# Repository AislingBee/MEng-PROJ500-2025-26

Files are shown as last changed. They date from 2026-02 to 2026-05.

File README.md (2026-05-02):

# MEng-PROJ500-2025-26

Main repository for the PROJ500 humanoid robot project.

Project timeline: December 2025 to May 2026.

## Start Here

1. Read this file for the project map.
2. Read [README_PROJECT_MAP.md](README_PROJECT_MAP.md) for a top-level file/folder map.
3. Read [README_IMPORTANT_PATHS.md](README_IMPORTANT_PATHS.md) for key entrypoints and files.
4. Read [README_QUICKSTART.md](README_QUICKSTART.md) for launch order and runtime checks.
5. For simulation and Isaac workflow, read [simulation/README.md](simulation/README.md).
6. For ROS2 motor stack, read [Software/src/motor_control/README.md](Software/src/motor_control/README.md).
7. For the RCU UDP protocol handover, read [Charlie/STM32Cube/Tools/ROS2/HANDOVER_INSTRUCTIONS.md](Charlie/STM32Cube/Tools/ROS2/HANDOVER_INSTRUCTIONS.md).

## Top-Level Repository Overview

## New STM32 Addition (RCU UDP Bridge)

The current hardware path now supports a direct STM32 RCU UDP binary bridge.

- New bridge node: [Software/src/motor_control/motor_control/bridges/rcu_udp_bridge.py](Software/src/motor_control/motor_control/bridges/rcu_udp_bridge.py)
- RCU launch entrypoint: [Software/src/motor_control/launch/rcu_launch.py](Software/src/motor_control/launch/rcu_launch.py)
- Full RL launch (with RCU transport): [Software/src/motor_control/launch/rl_robot_launch.py](Software/src/motor_control/launch/rl_robot_launch.py)
- Protocol reference and handover: [Charlie/STM32Cube/Tools/ROS2/HANDOVER_INSTRUCTIONS.md](Charlie/STM32Cube/Tools/ROS2/HANDOVER_INSTRUCTIONS.md)

RCU network defaults:

- RCU IP: `192.168.100.10`
- Thor host IP: `192.168.100.20/24`
- Telemetry in: UDP `7700`
- Command out: UDP `7701`
- Supervision out: UDP `7702`

The Software Nucleo bridge path has been removed; RCU UDP is now the primary integration path.

### Core folders

- [simulation](simulation): Isaac Sim assets, tools, and RL workspace.
  - Further docs:
  - [simulation/README.md](simulation/README.md)
  - [simulation/docs/README.md](simulation/docs/README.md)
  - [simulation/isaac/README.md](simulation/isaac/README.md)
  - [simulation/isaac/rl/README.md](simulation/isaac/rl/README.md)

- [Software](Software): software stack for firmware, bridge tools, ROS2 motor test package, and configs.
  - ROS2 motor package:
  - [Software/src/motor_control/README.md](Software/src/motor_control/README.md)
  - Integration guide:
  - [Software/ROS_STM32_INTEGRATION.md](Software/ROS_STM32_INTEGRATION.md)

### Top-level files

- [README.md](README.md): this overview.
- [joint_limit_results.csv](joint_limit_results.csv): saved joint limit validation/test output.
- [hardware/thor/thor_policy_runner.py](hardware/thor/thor_policy_runner.py): policy runtime script.
- [power_shell_commands](power_shell_commands): command notes and helper snippets.

## Software Folder Details

Within [Software](Software):

- [Software/config](Software/config): shared config files (including JSON config used by launch files).
- [Software/nucleo](Software/nucleo): motor protocol notes/manual assets and experimental scripts.
- [Software/src/motor_control](Software/src/motor_control): ROS2 package for command generation, bridges, listeners, and launch files.

## Important Readme and Documentation Index

### Simulation and RL

- [simulation/README.md](simulation/README.md)
- [simulation/docs/README.md](simulation/docs/README.md)
- [simulation/isaac/README.md](simulation/isaac/README.md)
- [simulation/isaac/rl/README.md](simulation/isaac/rl/README.md)

### Firmware and Bridge

- [Software/ROS_STM32_INTEGRATION.md](Software/ROS_STM32_INTEGRATION.md)
- [Charlie/STM32Cube/Tools/ROS2/HANDOVER_INSTRUCTIONS.md](Charlie/STM32Cube/Tools/ROS2/HANDOVER_INSTRUCTIONS.md)

### ROS2 Motor Test

- [Software/src/motor_control/README.md](Software/src/motor_control/README.md)
- Launch files are in [Software/src/motor_control/launch](Software/src/motor_control/launch).
- Test and bridge nodes are in [Software/src/motor_control/motor_control](Software/src/motor_control/motor_control).

## Contribution Rules

- Do not push directly to main.
- Use feature branches and open a pull request.
- Include a clear summary of changes and test steps in each PR.
- Merge to main only after review.
- Delete merged branches.

## Commit and PR Conventions

- Use descriptive commit titles (example: Add ROS2 joint command bridge).
- Include test evidence in PR descriptions.
- Provide exact run steps and expected output for reviewers.

Example test flow:

```bash
cd Software/src/motor_control
colcon build --packages-select motor_control
source install/setup.bash
ros2 launch motor_control rl_robot_launch.py
```

## Team

- Mechanical Lead (Project Lead): Brendan
- Electrical Lead: Charlie
- Simulation Lead: Joe
- Software/ROS Lead: Ash

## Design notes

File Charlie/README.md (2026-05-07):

# PROJ500 Humanoid Robot — Charlie's Handover

**Author:** Charlie  
**Date:** May 2026  
**Project:** MEng PROJ500 — Plymouth Humanoid Robot  

This folder contains all hardware and firmware deliverables produced during the 2025–26 academic year. It is structured into three top-level areas:

```
Charlie/
├── KiCad/                  — PCB schematics and layouts (5 boards)
├── PROJ500_PDU_FPGA/       — Lattice MachXO2 FPGA project (PDU sequencer)
└── STM32Cube/              — STM32 firmware (PDU + RCU) and PC tools
```

---

## System Overview

The robot's electronic architecture is split across two custom boards:

| Board | MCU | Role |
|---|---|---|
| **PDU** — Power Distribution Unit | STM32G474 | Battery management, power sequencing, relay/contactor control via FPGA |
| **RCU** — Real-Time Control Unit | STM32H723 | Motor CAN buses, Ethernet UDP to Thor, dual IMU, PDU telemetry forwarding |

The PDU and RCU communicate over a dedicated **management CAN bus (250 kbps)**. The RCU talks to the Thor AI computer (Jetson/PC) over **UDP/Ethernet**. Motors are driven by the RCU over two **1 Mbps CAN buses** using the RobStride RS04 private protocol.

```
[ Battery ] → [ PDU ] ──CAN(250k)──→ [ RCU ] ──Ethernet(UDP)──→ [ Thor / ROS2 ]
                 ↑FPGA                    ↓ ↑
               sequencer              FDCAN1/3 (1Mbps)
                                    [ 12× RS04 Motors ]
```

---

## 1. KiCad — PCB Designs

All boards were designed in **KiCad**. Each folder contains the full KiCad project (`.kicad_sch`, `.kicad_pcb`, `.kicad_pro`), a rendered **PDF schematic**, exported **STEP** 3D model, **BOM** (bill of materials in `bom/`), and **Gerber/drill files** for fabrication in `production/`.

### 1.1 Power Distribution Board (PDU)

**Folder:** `KiCad/PROJ500 - Power Distribution Board/`

The most complex board. Manages all power rails from the battery pack and implements hardware safety logic.

**Key schematics:**
| Sub-sheet | File | Description |
|---|---|---|
| Top level | `PROJ500 - Power Distribution Board.kicad_sch` | Hierarchy root |
| MCU | `MCU.kicad_sch` | STM32G474 with FDCAN1 (management CAN), I2C4 (FPGA), UART3/4 (RS485, debug), ADC, SWD debug header |
| FPGA | `FPGA.kicad_sch` | Lattice MachXO2-256HC-5SG48C QFN48 — relay sequencer + I2C slave |
| Safety logic | `safety_logic.kicad_sch` | Hardware e-stop and overvoltage/undervoltage comparators feeding FPGA inputs |
| Comparators | `Comparators.kicad_sch` | OV/UV sense circuits |
| Coil driver | `Coil_Driver.kicad_sch` | Relay coil drive circuit (K_EN / K_SEL) |
| Aux outputs | `Aux_Outputs.kicad_sch` | Auxiliary 12 V/24 V switched outputs, buzzer, status LEDs |

**Power rails** — refer to `PROJ500 - Power Distribution Board.pdf` for the confirmed rail architecture and voltage levels.

**ADC channels (TLA2528, I2C, address 0x17):**
| CH | Signal | Scaling |
|---|---|---|
| 0 | V_VRAW | ÷31 |
| 1 | I_VRAW_SW | 9.47× shunt amp |
| 2 | V_12V_SW | ÷7.8 |
| 3 | V_24V_SW | ÷14 |
| 4 | I_12V_SW | 4× shunt amp |
| 5 | I_24V_SW | 4× shunt amp |
| 6 | THERM1 | NTC β-model |
| 7 | THERM2 | NTC β-model |

**Local STM32G474 ADC pins:**
| Pin | Signal |
|---|---|
| PA6 ADC2_CH3 | Board thermistor 0 |
| PA7 ADC2_CH4 | Board thermistor 1 |
| PC4 ADC2_CH5 | Board thermistor 2 |
| PB0 ADC1_CH15 | V_SOURCE (36.71× divider) |
| PB1 ADC1_CH12 | V_BUS (36.71× divider) |
| PB2 ADC2_CH12 | I_COIL (2× shunt amp, 10 mΩ / ×50) |

---

### 1.2 Real-Time Control Unit (RCU)

**Folder:** `KiCad/PROJ500 - Real-Time Control Unit/`

**Key schematics:**
| Sub-sheet | File | Description |
|---|---|---|
| MCU | `STM32_MCU.kicad_sch` | STM32H723VGT6, FDCAN1/2/3, SPI3/4 (IMUs), Ethernet RMII |
| Ethernet | `ETHERNET.kicad_sch` | RJ45 + magnetics |
| ETH PHY | `ETH_PHY.kicad_sch` | PHY chip (RMII mode) |
| IMU | `IMU.kicad_sch` | Dual LSM6DSOX IMUs on SPI3/4 |
| ESP32 | `ESP32_MCU.kicad_sch` | Co-processor / future wireless |

A **production-ready Gerber zip** (`PROJ500 - Real-Time Control Unit.zip`) is included for direct upload to a PCB manufacturer.

---

### 1.3 Power Supply Board

**Folder:** `KiCad/PROJ500 - Power Supply Board/`

Standalone DC-DC converter board providing regulated rails from a high-voltage input.

**Converters:**
| File | Part | Output |
|---|---|---|
| `AP62200 - 5V 2A.kicad_sch` | AP62200 | 5 V / 2 A |
| `MIC28517 - 12V 4A.kicad_sch` | MIC28517 | 12 V / 4 A |
| `MIC28517 - 24V 8A.kicad_sch` | MIC28517 | 24 V / 8 A |
| `SiC437 - 12V 8A.kicad_sch` | SiC437 | 12 V / 8 A (high efficiency) |
| `Hot Swap Switch.kicad_sch` | TPS249x | Hot-swap / inrush limiting |
| `Shunt Amplifiers.kicad_sch` | — | Current sense amps |
| `TLA2528 ADC.kicad_sch` | TLA2528 | 8-ch ADC for rail monitoring |

A **TPS249x design spreadsheet** (`TPS249x_8x_Design_Calculator_REV_B.xlsx`) is included for recalculating hot-swap component values.

---

### 1.4 Auxiliary IMU Board

**Folder:** `KiCad/PROJ500 - Auxillary IMU Board/`

Compact breakout board for a single IMU (e.g. LSM6DSOX). Intended for body segments that cannot fit the main RCU.

---

### 1.5 Braking Chopper Controller

**Folder:** `KiCad/PROJ500 - Braking Chopper Controller/`

Handles regenerative braking energy from motors. Dissipates or redirects back-EMF during deceleration to protect the bus capacitors.

---

## 2. PROJ500_PDU_FPGA — Lattice MachXO2 FPGA

**Tool required:** Lattice Diamond (tested with 3.13)  
**Device:** MachXO2-256HC-5SG48C (SG48C QFN48 package)  
**Clock:** Internal OSCH @ 2.08 MHz  

### 2.1 Source Files

| File | Description |
|---|---|
| `pdu_glue_mxo2.sv` | **Main production image** — full relay sequencing FSM + EFB I2C slave |
| `pdu_selftest_mxo2.sv` | **Board self-test image** — drives all outputs for PCB bring-up continuity checks |
| `PDU_EFB_I2C.v` / `.edn` | Lattice EFB I2C slave instantiation (auto-generated from Diamond IP) |
| `PROJ500_PDU_FPGA.lpf` | Pin Location File — maps all signal names to physical QFN48 pins |
| `PROJ500_PDU_FPGA.ldf` | Diamond project file |
| `pdu_glue_synth.sdc` | Timing constraints (2.08 MHz clock constraint) |
| `tb_pdu_glue.sv` | Simulation testbench for the main FSM |
| `tb_pdu_selftest_mxo2.sv` | Simulation testbench for the self-test image |
| `sim_do.do` | ModelSim run script |

### 2.2 FPGA State Machine

The FPGA implements the main contactor and precharge relay sequencer:

| State | STATE_CODE | Description |
|---|---|---|
| ST_IDLE | 0 | All outputs de-asserted, waiting for SW_COMPUTE |
| ST_COMPUTE | 3 | SW_COMPUTE=1, awaiting arm permission |
| ST_PRECHARGE | 1 | Relay closed on NC (precharge) path; charging bus |
| ST_PRECHARGE_ABORT | 1 | Relay held closed while bus discharges safely |
| ST_ARMED | 2 | Main contactor closed, motors active |
| ST_FAULT | 0 | Latched fault — requires manual SW_RST_FAULT |

**Relay control note:** `K_SEL=0` selects the **precharge (NC) path**; `K_SEL=1` selects the **dump path**. Always verify polarity on the bench before first energisation.

### 2.3 FPGA I2C Register Map

The FPGA exposes a read-only I2C slave at **address 0x55** (7-bit):

| Register | Address | Description |
|---|---|---|
| STATUS0 | 0x00 | Fault/status flags bitmask |
| FAULT_CODE | 0x01 | Fault reason code |
| STATE_CODE | 0x02 | FSM state (0=IDLE, 1=PCHG, 2=ARMED, 3=COMPUTE) |
| ACTIONS | 0x03 | Current output action register |
| INPUTS | 0x04 | Latched input states (e-stop, arm flags) |
| PCHG_HI | 0x05 | Precharge timer high byte |
| PCHG_LO | 0x06 | Precharge timer low byte |
| VERSION | 0x7F | FPGA firmware version |

### 2.4 Built Implementations

Two ready-to-program bitfiles are included:

| Implementation | Folder | Bitfile | JEDEC |
|---|---|---|---|
| Production (V1) | `V1/` | `PROJ500_PDU_FPGA_V1.bit` | `PROJ500_PDU_FPGA_V1.jed` |
| Self-test | `SELFTEST/` | `PROJ500_PDU_FPGA_SELFTEST.bit` | `PROJ500_PDU_FPGA_SELFTEST.jed` |

### 2.5 FPGA JTAG Programming (FT2232H)

Connect a FT2232H development board to the FPGA JTAG header (02×05 IDC):

| IDC Pin | Signal | FT2232H (ADBUS) |
|---|---|---|
| 1 | TCK | ADBUS0 |
| 2 | GND | GND |
| 3 | TMS | ADBUS3 |
| 4 | GND | GND |
| 5 | TDI | ADBUS1 |
| 6 | 3V3 | 3V3 |
| 7 | TDO | ADBUS2 |
| 8 | GND | GND |

Use Diamond Programmer or `openFPGALoader` with the `.jed` or `.bit` file.

---

## 3. STM32Cube — Firmware and Tools

### 3.1 MCU_PDU_V1 — PDU Firmware

**Target:** STM32G474RET6 (LQFP64)  
**IDE:** STM32CubeIDE  
**Project file:** `STM32Cube/MCU_PDU_V1/MCU_PDU_V1.ioc`  

The PDU runs a **bare-metal superloop** (no RTOS). All modules expose an `_init()` / `_tick()` API called from `pdu_app.c`.

#### Source Modules

| File | Description |
|---|---|
| `main.c` | CubeMX-generated HAL init; calls `PDU_App_Init()` then loops `PDU_App_Task()` |
| `pdu_app.c` | Superloop coordinator — sequences all subsystem ticks |
| `fpga_mon.c` | Polls FPGA I2C registers every ~50 ms; caches in `fpga_snapshot_t` |
| `pdu_adc.c` | Samples TLA2528 (I2C4, ext ADC) and local STM32 ADC channels |
| `ssd_energy.c` | Queries SSD RS485 energy meter over USART3 at 19200 baud (~5 Hz) |
| `pdu_mcan_app.c` | Management CAN TX/RX on FDCAN1 (250 kbps); sends telemetry to RCU |
| `pdu_selftest_cli_v3.c` | UART self-test CLI (build-mode selectable) |

#### Management CAN Frame IDs (PDU → RCU)

| CAN ID | Rate | Content |
|---|---|---|
| 0x511 | 2 Hz | PDU heartbeat |
| 0x520 | 10 Hz | FPGA status (status0, fault, state, actions, inputs, version, pchg) |
| 0x521 | 10 Hz | Power rail voltages (V_RAW, 12 V, 24 V) |
| 0x522 | 10 Hz | Rail currents + thermistors |
| 0x523 | 5 Hz | SSD energy meter (I, V, P, T) |
| 0x524 | 10 Hz | Local ADC A (board therms 0–2, V_SOURCE) |
| 0x525 | 10 Hz | Local ADC B (V_BUS, I_COIL) |

**RCU → PDU:**

| CAN ID | Content |
|---|---|
| 0x530 | AUX switch command (bits[2:0]=CH3/2/1, bit3=buzz, bit4=LED blink) |
| 0x531 | CMD_FAULT request (bit0=assert, bit1=clear) |

#### STLink Debug Header (02×05 IDC)

| IDC Pin | Signal | Wire colour |
|---|---|---|
| 1 | 3.3 V | Red |
| 2 | SWDIO | Yellow |
| 3 | GND | Black |
| 4 | SWCLK | Green |
| 5 | GND | Black |
| 6 | SWO | Blue |
| 7 | UART_RX | Brown |
| 8 | UART_TX | Grey |
| 9 | 5 V | Purple |
| 10 | NRST | White |

---

### 3.2 MCU_RCU_V1 — RCU Firmware

**Target:** STM32H723VGT6 (LQFP100)  
**IDE:** STM32CubeIDE  
**Project file:** `STM32Cube/MCU_RCU_V1/MCU_RCU_V1.ioc`  

Also a **bare-metal superloop**. All modules expose `_init()` / `_tick()` called from `rcu_app.c`.

#### Source Modules

| File | Description |
|---|---|
| `main.c` | HAL init; calls `RCU_App_Init()` then loops `RCU_App_Task()` |
| `rcu_app.c` | Superloop coordinator; scheduling buckets at 10 Hz and 200 Hz |
| `motor_bus.c` | FDCAN1 (right) + FDCAN3 (left) motor CAN; drains RX FIFOs, caches feedback |
| `rs04.c` | RobStride RS04 CAN codec — pure, no HAL dependency |
| `imu.c` | Dual LSM6DSOX on SPI3/4 at 416 Hz ODR; DRDY interrupt driven |
| `eth_udp.c` | lwIP raw-API UDP sockets; TX/RX on ports 7700/7701/7702 |
| `mcan_pdu.c` | Receives PDU telemetry over FDCAN2 (management CAN); caches in `pdu_telem_t` |
| `telem_pack.c` | Assembles UDP packets from live subsystem data; dispatches inbound motor commands |
| `rcu_pkt.h` | All UDP packet type definitions and structs (source of truth for the protocol) |
| `rcu_selftest_cli_v1.c` | UART self-test CLI |

#### Motor Bus Mapping (12-DOF Lower Body)

| Motor ID | Joint | Bus |
|---|---|---|
| 1 | pelvis_link_l_yaw_joint | LEFT (FDCAN3) |
| 2 | pelvis_link_r_yaw_joint | RIGHT (FDCAN1) |
| 3 | l_hip_yaw_link_l_pitch_joint | LEFT |
| 4 | r_hip_yaw_link_r_pitch_joint | RIGHT |
| 5 | l_hip_pitch_link_l_roll_joint | LEFT |
| 6 | r_hip_pitch_link_r_roll_joint | RIGHT |
| 7 | l_thigh_link_l_knee_joint | LEFT |
| 8 | r_thigh_link_r_knee_joint | RIGHT |
| 9 | l_shank_link_l_ankle_joint | LEFT |
| 10 | r_shank_link_r_ankle_joint | RIGHT |
| 11 | l_ankle_link_l_foot_joint | LEFT |
| 12 | r_ankle_link_r_foot_joint | RIGHT |

#### IMU Configuration

| | IMU0 | IMU1 |
|---|---|---|
| SPI bus | SPI4 (PE2/5/6) | SPI3 (PC10/11/12) |
| Chip Select | PC13 | PA15 |
| DRDY / INT1 | PE3 (EXTI3) | PA9 (EXTI9_5) |
| ODR | 416 Hz | 416 Hz |
| Accel range | ±4 g (0.122 mg/LSB) | same |
| Gyro range | ±500 dps (17.5 mdps/LSB) | same |
| Temp | raw/256 + 25 → °C | same |

#### Network Configuration

| Parameter | Value |
|---|---|
| RCU static IP | `192.168.100.10` |
| Thor IP | `192.168.100.20` |
| Subnet mask | `255.255.255.0` |
| Telem TX port (RCU→Thor) | 7700 |
| Cmd RX port (Thor→RCU) | 7701 |
| Supervision TX port (RCU→Thor) | 7702 |

---

### 3.3 UDP Binary Protocol Reference

Full detail is in `STM32Cube/MCU_RCU_V1/THOR_INTERFACE.md` and `STM32Cube/Tools/ROS2/HANDOVER_INSTRUCTIONS.md`. Summary below.

**Packet header (6 bytes, all packets):**
```
[0:1]  magic  = 0x5243  ('RC' little-endian)
[2]    type   — see below
[3]    seq    — rolling 0–255
[4:5]  len    — payload bytes (LE uint16)
```

**Packet types:**

| Type | Direction | Rate | Description |
|---|---|---|---|
| 0x01 | RCU → Thor | 10 Hz | Slow telemetry (PDU power, therms, SSD, IMU) — 72 bytes |
| 0x02 | RCU → Thor | 200 Hz | Motor feedback (pos, vel, torque, error) — 4 + n×10 bytes |
| 0x03 | RCU → Thor | on-change | Supervision events |
| 0x04 | RCU → Thor | 200 Hz | Fast IMU packet (28 bytes) — **primary RL loop IMU source** |
| 0x10 | Thor → RCU | 200 Hz | Motor command (n × 10 bytes) |
| 0x11 | Thor → RCU | on-demand | Motor supervisory (enable mask, ctrl_mode, fault clear) |
| 0x20 | Thor → RCU | on-demand | Debug command (ping, buzz, LED, CAN loopback, soft reset, etc.) |
| 0x21 | RCU → Thor | on-demand | Debug reply |

**Motor command encoding (uint16 on wire):**
```
value_raw = int((value - min) / (max - min) * 65535)
```
| Quantity | Min | Max |
|---|---|---|
| Position | −12.57 rad | +12.57 rad |
| Velocity | −15 rad/s | +15 rad/s |
| Torque | −120 N·m | +120 N·m |

Mid-scale (32767) = zero for position, velocity, and torque.

**Motor supervisory packet (Type 0x11) — enable all motors in CSP mode:**
```python
import struct
payload = struct.pack("<HHBxxx", 0x0FFF, 0x0FFF, 1)  # enable + CSP
```

**Full e-stop:**
```python
payload = struct.pack("<HHBxxx", 0x0000, 0x0000, 1)
```

---

### 3.4 Shared Library

**Folder:** `STM32Cube/Shared/`

| File | Description |
|---|---|
| `Inc/st_mcan.h` | Shared FDCAN helper types and wrappers |
| `Src/st_mcan.c` | Implementation |
| `Inc/st_common.h` | Common defines shared between PDU and RCU firmware |

Both CubeIDE projects reference these files so changes propagate to both builds automatically.

---

### 3.5 Tools — Python Bench Utilities

**Folder:** `STM32Cube/Tools/`

| File | Description |
|---|---|
| `plymouth_humanoid_bench_monitor.py` | **Bench monitoring GUI** — connects to RCU UDP port 7700, plots live power rails, IMU data, thermal readings with configurable alerts |
| `bench_config.json` | GUI configuration — IP, display settings, alert thresholds, recorded signal list |
| `ROS2/rcu_udp_bridge.py` | **ROS2 bridge node** — replaces the old `ethernet_can_bridge.py` / `nucleo_can_bridge` serial bridge; subscribes `/robot_command`, publishes `/motor_can_feedback`, `/imu0`, `/imu1`, `/rcu_pdu_telem`; exposes `/rcu_motor_estop` and `/rcu_pdu_fault` services |
| `ROS2/rcu_launch.py` | ROS2 launch file for the full motor control stack |
| `ROS2/HANDOVER_INSTRUCTIONS.md` | **Complete Thor integration guide** — read this first when integrating with ROS2 |

#### Running the Bench Monitor (Windows/Linux)

```bash
pip install pyqt5 pyqtgraph
python plymouth_humanoid_bench_monitor.py
```

Set your PC NIC to static IP `192.168.100.20/24`. The GUI reads `bench_config.json` from the same directory.

#### Running the ROS2 Bridge

```bash
# Basic launch
ros2 launch <your_package> rcu_launch.py

# With arguments
ros2 launch <your_package> rcu_launch.py rcu_ip:=192.168.100.10 ctrl_mode:=1
```

**ctrl_mode values:**
- `1` = CSP position mode (Phase 1 — simpler, recommended first)
- `0` = MIT impedance mode (Phase 2 — full torque/velocity/gain control)

> **Package name:** Update `<your_ros2_package>` in `rcu_launch.py` to match your ROS2 workspace package before running.

---

## 4. Key Integration Notes

### 4.1 First Power-On Sequence

1. Program the FPGA with the **SELFTEST** bitfile (`SELFTEST/PROJ500_PDU_FPGA_SELFTEST.jed`) first to verify PCB continuity.
2. Verify all output pins toggle correctly with a scope or logic analyser.
3. Once hardware is confirmed, re-program with the **V1 production** bitfile (`V1/PROJ500_PDU_FPGA_V1.jed`).
4. Flash the PDU MCU firmware (`MCU_PDU_V1`) and check UART self-test output via the STLink header.
5. Flash the RCU MCU firmware (`MCU_RCU_V1`). Run `RCU_SelfTest` via UART to verify CAN loopback, IMU WHO_AM_I, and Ethernet link.

### 4.2 Relay Polarity Warning

> **CRITICAL:** Verify `K_SEL` polarity on the bench with a multimeter **before** enabling `K_EN` for the first time. A wiring error will connect the dump resistor during precharge (inadequate inrush protection) or the precharge resistor during dump (insufficient energy dissipation). The K_SEL blanking time (30 ms) does not protect against a polarity error.

### 4.3 Motor Enable Procedure

Motors must be explicitly enabled before motion commands are accepted. Use the RCU debug command or supervisory packet:

```python
# Via UDP debug command (bench testing without ROS2)
import socket, struct
sock = socket.socket(socket.AF_INET, socket.SOCK_DGRAM)
# Enable motor_id=1 on its mapped bus, clear fault
payload = bytes([0x0C, 0, 1, 1, 1])  # MOTOR_ENABLE: bus=0, id=1, enable=1, clr_fault=1
hdr = struct.pack("<HBBh", 0x5243, 0x20, 0, len(payload))
sock.sendto(hdr + payload, ("192.168.100.10", 7701))
```

### 4.4 RS04 Motor Protocol Notes

- All RS04 CAN frames use **29-bit extended IDs** at 1 Mbps.
- The host (RCU) CAN ID is `0xFD`.
- `mode_status` in feedback (bits [23:22] of CAN ID): `0`=reset, `1`=calibrating, `2`=MIT running. A motor ready to accept commands will show `mode_status=2`.
- CSP position mode is configured via RS04 Type-18 parameter write (`RS04_PARAM_RUN_MODE = 0x7005`, value `5.0f`). The codec helper is in `rs04.c`.

### 4.5 Old Bridge — Superseded

The old `ethernet_can_bridge.py` + `nucleo_can_bridge` (serial CAN bridge via STM32 Nucleo) is **fully superseded** by `rcu_udp_bridge.py`. Do not attempt to run both simultaneously.

---

## 5. Software Requirements

### Firmware (STM32CubeIDE)
- **STM32CubeIDE** ≥ 1.14 (includes GCC ARM toolchain)
- HAL drivers are included in the project (`Drivers/` folders) — no external downloads needed

### FPGA (Lattice Diamond)
- **Lattice Diamond** ≥ 3.12 for synthesis and programming
- `openFPGALoader` can be used as an alternative programmer with the `.jed` files

### Python Tools
```
Python ≥ 3.9
pyqt5         (bench monitor GUI)
pyqtgraph     (bench monitor plots)
rclpy         (ROS2 bridge — ROS2 Humble or later)
```

### ROS2 Topics Published by `rcu_udp_bridge`

| Topic | Type | Rate | Description |
|---|---|---|---|
| `/motor_can_feedback` | `UInt8MultiArray` | 200 Hz | 8 bytes/motor (float32 pos + float32 vel), motors 1→12, 96 bytes total |
| `/imu0` | `sensor_msgs/Imu` | 200 Hz | IMU0 in ROS2 body frame (X=fwd, Y=left, Z=up) |
| `/imu1` | `sensor_msgs/Imu` | 200 Hz | IMU1 in ROS2 body frame |
| `/rcu_pdu_telem` | `std_msgs/String` | 10 Hz | JSON-encoded PDU telemetry snapshot |

---

## 6. File Quick-Reference

| What you need | Where to find it |
|---|---|
| PDU schematic PDF | `KiCad/PROJ500 - Power Distribution Board/PROJ500 - Power Distribution Board.pdf` |
| RCU schematic PDF | `KiCad/PROJ500 - Real-Time Control Unit/PROJ500 - Real-Time Control Unit.pdf` |
| Power Supply schematic PDF | `KiCad/PROJ500 - Power Supply Board/PROJ500 - Power Supply Board.pdf` |
| PDU Gerbers | `KiCad/PROJ500 - Power Distribution Board/production/` |
| RCU Gerbers (zip) | `KiCad/PROJ500 - Real-Time Control Unit/PROJ500 - Real-Time Control Unit.zip` |
| FPGA production bitfile | `PROJ500_PDU_FPGA/V1/PROJ500_PDU_FPGA_V1.jed` |
| FPGA self-test bitfile | `PROJ500_PDU_FPGA/SELFTEST/PROJ500_PDU_FPGA_SELFTEST.jed` |
| FPGA pinout | `PROJ500_PDU_FPGA/PROJ500_PDU_FPGA.lpf` |
| UDP protocol spec | `STM32Cube/MCU_RCU_V1/THOR_INTERFACE.md` |
| ROS2 integration guide | `STM32Cube/Tools/ROS2/HANDOVER_INSTRUCTIONS.md` |
| STLink wiring | `STM32Cube/STLINK - 02x05 IDC HEADER.txt` |
| FPGA JTAG wiring | `PROJ500_PDU_FPGA/FPGA JTAG - 02x05 IDC HEADER.txt` |
| Bench monitor config | `STM32Cube/Tools/bench_config.json` |

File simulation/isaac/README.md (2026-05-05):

# Isaac Sim Environment

This directory contains all assets and scripts related to the simulation
environment.

It defines the physical behaviour of the humanoid robot within the simulator,
including kinematics, dynamics, sensors, and terrain interaction. This folder
is independent of reinforcement learning logic.

## Scope
- Robot definition (URDF and USD)
- Meshes, textures, and collision geometry
- Sensor configuration
- Low-level control interfaces
- Simulation helper scripts

# URDF → USD → Isaac Lab Pipeline

This folder contains utility scripts used to convert the humanoid from **Fusion → URDF → USD → Isaac Lab**, and to validate that the robot spawns correctly as a PhysX articulation.

## Overview

The workflow is:

1. Clean floating-point noise in the URDF
2. Convert URDF → USD using Isaac Lab
3. Apply post-fixes (defaultPrim, articulation root, upright rotation)
4. Spawn robot in a minimal Isaac Lab scene to validate simulation

This keeps the simulation pipeline reproducible and deterministic.

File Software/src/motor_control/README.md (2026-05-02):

# Software
This folder contains the ROS2 software used to communicate with hardware controllers and sensors.

## Folder Contents:

ros2 motor test 1 drawio

## Launch Files:
### Main launch entrypoints

- `rl_robot_launch.py`: full RL-to-hardware pipeline using the STM32 RCU UDP bridge.
- `rcu_launch.py`: minimal RCU-focused launch entrypoint for bring-up and diagnostics.

### New STM32 RCU addition

The project now supports direct UDP binary communication with the STM32H723 RCU.

- Transport node: `motor_control/bridges/rcu_udp_bridge.py`
- Command topic: `/robot_command`
- Feedback topic: `/motor_can_feedback`
- IMU topics: `/imu0` and `/imu1`
- Observation output: `/robot_observation`

Default RCU network settings:

- `rcu_ip`: `192.168.100.10`
- `rcu_cmd_port`: `7701`
- `telem_port`: `7700`
- `ctrl_mode`: `1` (CSP phase)

Reference protocol and handover document:

- `Charlie/STM32Cube/Tools/ROS2/HANDOVER_INSTRUCTIONS.md`

Params that may be changed as needed:

- UDP transport settings (IP and ports)
- joint/CAN mapping settings
- gains (`kp`, `kd`) and test profile settings

Safety-critical controls exposed by the RCU bridge:

- `/rcu_motor_estop` (`std_srvs/SetBool`)
	- `true`: enable motors
	- `false`: full e-stop (motor disable plus PDU fault assert)
- `/rcu_pdu_fault` (`std_srvs/SetBool`)
	- `true`: assert PDU fault
	- `false`: clear PDU fault

## How to Run ROS2:

```bash
source /opt/ros/jazzy/setup.bash
```

```
cd Software
colcon build --packages-select motor_control
source install/setup.bash
ros2 launch motor_control rl_robot_launch.py
```

Optional RCU-only launch:

```bash
ros2 launch motor_control rcu_launch.py
```

For additional launch examples and runtime commands, see `Software/TERMINAL_COMMANDS.md`.

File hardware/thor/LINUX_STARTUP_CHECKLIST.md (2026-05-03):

# THOR Linux Startup Checklist (RL Policy Runner)

Use this checklist when bringing up the full THOR RL-to-hardware loop on Linux.

## 0. Preflight (one-time or after reboot)

- [ ] Thor host and RCU are on the same subnet.
- [ ] Expected network defaults:
  - RCU IP: `192.168.100.10`
  - Thor host IP: `192.168.100.20/24`
  - Telemetry UDP: `7700`
  - Command UDP: `7701`
- [ ] Robot is in a safe stance with mechanical clearance.
- [ ] E-stop path is physically reachable.

Optional quick network check:

```bash
ping -c 3 192.168.100.10
```

## 1. Build and source ROS workspace

From repo root:

```bash
source /opt/ros/jazzy/setup.bash
cd Software
colcon build --packages-select motor_control --symlink-install
source install/setup.bash
```

## 2. Launch hardware ROS pipeline (Terminal A)

### Option A — One command (recommended)

Starts RCU stack + `startup_then_policy_runner.py` together. `PYTHONPATH` is set automatically.

```bash
source /opt/ros/jazzy/setup.bash
cd Software
source install/setup.bash
ros2 launch motor_control thor_12_motor_pipeline_launch.py
```

### Option B — Two terminals (manual)

```bash
source /opt/ros/jazzy/setup.bash
cd Software
source install/setup.bash
ros2 launch motor_control rl_robot_launch.py
```

This should start:
- `rcu_udp_bridge`
- `motor_feedback_listener`
- `robot_observation_bridge`

## 3. Verify topics are alive (Terminal B)

```bash
source /opt/ros/jazzy/setup.bash
cd Software
source install/setup.bash

ros2 topic list | grep -E "robot_command|robot_observation|motor_can_feedback|imu0"
ros2 topic hz /robot_observation
ros2 topic hz /imu0
```

Expected:
- `/robot_observation` and `/imu0` publish steadily.
- No repeated timeout/errors from bridge nodes.

## 4. Start startup + policy runner (Terminal C)

> **Skip if using Option A above — `startup_then_policy_runner.py` is launched automatically.**

From repo root:

```bash
source /opt/ros/jazzy/setup.bash
cd Software
source install/setup.bash
cd ..
export PYTHONPATH=$(pwd):$PYTHONPATH
python3 hardware/thor/startup_then_policy_runner.py
```

Policy runner defaults:
- Command topic: `/robot_command`
- Observation topic: `/robot_observation`
- Node: `thor_policy_runner`
- Policy file: `exports/standing_policy.pt`

## 5. Runtime checks

In another terminal:

```bash
source /opt/ros/jazzy/setup.bash
cd Software
source install/setup.bash

ros2 topic hz /robot_command
ros2 topic echo /robot_command --once
ros2 topic echo /robot_observation --once
```

Expected:
- `/robot_command` publishes continuously while runner is active.
- Observation messages update and contain sensible values.

## 6. Safe stop

1. Stop policy runner first (`Ctrl+C` in Terminal C).
2. Stop launch pipeline (`Ctrl+C` in Terminal A).
3. Confirm command stream stops:

```bash
ros2 topic hz /robot_command
```

## 7. Fault recovery shortcuts

Use if needed after startup failures:

```bash
source /opt/ros/jazzy/setup.bash
cd Software
source install/setup.bash

# Enable motors
ros2 service call /rcu_motor_estop std_srvs/srv/SetBool "{data: true}"

# Full e-stop (disable motors + assert PDU fault)
ros2 service call /rcu_motor_estop std_srvs/srv/SetBool "{data: false}"

# Clear PDU fault
ros2 service call /rcu_pdu_fault std_srvs/srv/SetBool "{data: false}"
```

## 8. Common issues

- `ROS2 bridge dependencies are unavailable`:
  - Ensure ROS2 and `Software/install/setup.bash` are sourced in that terminal.
- No `/robot_observation`:
  - Check `rcu_udp_bridge` telemetry, RCU IP, and UDP port routing.
- Policy file load error:
  - Confirm `exports/standing_policy.pt` exists and is a deployable actor module (not raw training checkpoint dict).

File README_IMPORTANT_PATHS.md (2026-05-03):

# Important Files and Entry Points

Use this index when you need to quickly find the right place to edit or run.

## Core Docs

- `README.md`: Main project overview.
- `README_PROJECT_MAP.md`: Top-level structure map.
- `README_QUICKSTART.md`: Startup order and run commands.
- `Software/TERMINAL_COMMANDS.md`: Command reference.
- `Software/ROS_STM32_INTEGRATION.md`: ROS <-> STM32 protocol/integration notes.

## Policy Runner and Hardware Integration

- `hardware/thor/startup_then_policy_runner.py`: **Primary runtime script.** Handles startup ramp → standing hold → policy in one process.
- `hardware/thor/thor_policy_runner.py`: Standalone policy-only runner (no startup ramp; use after robot is already standing).
- `simulation/isaac/rl/interface/ros2_robot_bridge.py`: ROS2 bridge used by policy runner hooks.
- `simulation/isaac/rl/interface/robot_hardware_interface.py`: Hardware interface contract.

## ROS2 Launch and Nodes (motor_control)

- `Software/src/motor_control/launch/thor_12_motor_pipeline_launch.py`: **One-command** full 12-motor launch (RCU stack + policy runner, auto_enable, startup gate, PYTHONPATH set automatically).
- `Software/src/motor_control/launch/rl_robot_launch.py`: RL-ready 12-motor pipeline (policy runner started separately).
- `Software/src/motor_control/launch/rcu_launch.py`: Minimal RCU bridge bring-up launch.

- `Software/src/motor_control/motor_control/bridges/robot_command_bridge.py`: RobotCommand -> packed motor CAN payload.
- `Software/src/motor_control/motor_control/bridges/rcu_udp_bridge.py`: RCU UDP binary protocol bridge, publishes feedback and IMU.
- `Software/src/motor_control/motor_control/bridges/robot_observation_bridge.py`: Combines motor feedback + IMU into RobotObservation.
- `Software/src/motor_control/motor_control/sensors/motor_feedback_listener.py`: Decodes packed feedback topic.

## Shared Configuration

- `simulation/isaac/configuration/joint_limits_config.json`: Source of truth for joint names and limits.
- `Software/config/json/motor_names.json`: Legacy motor-name list format.
- `Software/config/json/MotorParams.json`: Motor parameter configuration.
- `Software/config/json/multi_state_test_config.json`: Multi-state test sequence config.

## Simulation and RL

- `simulation/README.md`: Simulation section overview.
- `simulation/isaac/README.md`: Isaac environment overview.
- `simulation/isaac/rl/README.md`: RL workspace overview.
- `simulation/isaac/runtime/thor_policy_runner_testbench.py`: Policy-runner testbench harness.

## Firmware and Bridge Docs

- `Charlie/STM32Cube/Tools/ROS2/HANDOVER_INSTRUCTIONS.md`: RCU protocol reference and integration handover.
- `Software/ROS_STM32_INTEGRATION.md`: RCU-side ROS integration notes.

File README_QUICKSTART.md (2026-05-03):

# Quickstart (Linux + ROS2 + Policy Runner)

This guide gives a practical order for bringing up the software stack and the Thor policy runner.

## 1) Source ROS2, build, and source workspace

From repository root:

```bash
source /opt/ros/jazzy/setup.bash
cd Software
colcon build --packages-select motor_control --symlink-install
source install/setup.bash
```

## 2) Launch ROS hardware pipeline

### Option A — One command (recommended)

Starts RCU stack + `startup_then_policy_runner.py` together. Handles ramp → standing hold → policy in one process:

```bash
ros2 launch motor_control thor_12_motor_pipeline_launch.py
```

Keyboard controls once running:
- `p` — advance from standing hold to policy
- `h` — return to standing hold
- `x` or Ctrl+C — safe exit

### Option B — Two terminals (manual control)

Terminal A — RCU stack:
```bash
ros2 launch motor_control rl_robot_launch.py
```

Terminal B — Startup + policy runner:
```bash
source /opt/ros/jazzy/setup.bash
cd Software
source install/setup.bash
cd ..
export PYTHONPATH=$(pwd):$PYTHONPATH
python3 hardware/thor/startup_then_policy_runner.py
```

This starts:
- Command bridge (`/robot_command` -> `/motor_can_tx`)
- Ethernet bridge (STM32 comms, motor feedback, STM32 IMU passthrough)
- Motor feedback listener (`/motor_can_feedback` -> `/motor_feedback`)
- Robot observation bridge (`/motor_feedback` + `/imu0` -> `/robot_observation`)

## 3) Runtime checks

```bash
ros2 topic list
ros2 topic echo /robot_observation
ros2 topic echo /imu0
ros2 topic echo /robot_command
```

## Notes

- Joint names are sourced from `simulation/isaac/configuration/joint_limits_config.json`.
- Per-joint CAN IDs are expected to map by joint order (first joint -> ID 1).

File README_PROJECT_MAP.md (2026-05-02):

# Project Map (Top Level)

This file is a quick map of the repository root and what each top-level item is for.

## Repository Root

- `.git/`: Git metadata.
- `.gitattributes`: Git attributes configuration.
- `.gitignore`: Ignore rules for generated/local files.
- `.idea/`: IDE workspace metadata.
- `README.md`: Main repository overview.
- `README_PROJECT_MAP.md`: This file.
- `README_QUICKSTART.md`: End-to-end startup guide.
- `README_IMPORTANT_PATHS.md`: Index of important files and entrypoints.
- `joint_limit_results.csv`: Joint-limit validation output snapshot.
- `power_shell_commands`: Command notes/snippets.

## Main Folders

- `simulation/`: Isaac simulation, assets, RL tasks, and tools.
- `hardware/`: Hardware-side runtime integration (including Thor policy runner).
- `Software/`: ROS2 nodes, launch files, bridge logic, and STM32 firmware workspace.

## Generated / Build Artifacts

- `build/`: Colcon build artifacts.
- `install/`: Colcon install overlay (`setup.ps1`, `local_setup.ps1`, etc.).
- `log/`: Colcon and runtime logs.

These are generated and usually should not be edited directly.

## Where To Start

- New to project: read `README.md` then `README_QUICKSTART.md`.
- Looking for key code locations: read `README_IMPORTANT_PATHS.md`.

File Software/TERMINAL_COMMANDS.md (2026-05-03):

# Terminal Commands Reference

All commands assume repo root: `c:\git\MEng-PROJ500-2025-26`

## 1. ROS 2 Build (motor_control)

```bash
source /opt/ros/jazzy/setup.bash
cd Software
colcon build --packages-select motor_control
source install/setup.bash
```

## 2. Launch Files (RCU Path)

```bash
# Full 12-motor one-command launch (RCU stack + startup ramp + standing hold + policy)
ros2 launch motor_control thor_12_motor_pipeline_launch.py

# RL-ready pipeline only (run startup_then_policy_runner.py manually in a second terminal)
ros2 launch motor_control rl_robot_launch.py

# Minimal RCU bridge bring-up
ros2 launch motor_control rcu_launch.py
```

> **Note:** `thor_12_motor_pipeline_launch.py` launches `startup_then_policy_runner.py` which
> handles ramp → hold → policy in one process. `PYTHONPATH` is set automatically so `simulation`
> is importable. No extra export needed.

## 3. Runtime Inspection

```bash
ros2 topic list
ros2 topic echo /robot_command
ros2 topic echo /motor_can_feedback
ros2 topic echo /robot_observation
ros2 topic hz /imu0
ros2 node list
```

## 4. Safety Services

```bash
# Enable all motors
ros2 service call /rcu_motor_estop std_srvs/srv/SetBool "{data: true}"

# Full e-stop (disable + PDU fault assert)
ros2 service call /rcu_motor_estop std_srvs/srv/SetBool "{data: false}"

# Assert PDU fault
ros2 service call /rcu_pdu_fault std_srvs/srv/SetBool "{data: true}"

# Clear PDU fault
ros2 service call /rcu_pdu_fault std_srvs/srv/SetBool "{data: false}"
```

## 5. Network Setup (Thor Host)

```bash
sudo ip addr add 192.168.100.20/24 dev eth0
sudo ip link set eth0 up
```

## 6. Troubleshooting Quick Checks

```bash
# Confirm RCU is reachable
ping 192.168.100.10

# Check IMU stream rate
ros2 topic hz /imu0

# Check motor feedback stream
ros2 topic echo /motor_can_feedback --no-arr
```

## 7. Reference

- `Software/src/motor_control/README.md`
- `Software/ROS_STM32_INTEGRATION.md`
- `Charlie/STM32Cube/Tools/ROS2/HANDOVER_INSTRUCTIONS.md`

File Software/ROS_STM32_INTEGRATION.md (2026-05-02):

# ROS <-> STM32 RCU Integration

## Status

The legacy Nucleo serial bridge path has been removed from `Software/`.
The active hardware integration is the STM32H723 RCU UDP binary bridge.

## Active Runtime Path

```text
thor_policy_runner.py (Ros2RobotBridge)
  -> /robot_command
  -> rcu_udp_bridge.py
  -> UDP 7701 (Thor -> RCU)

RCU
  -> UDP 7700 (RCU -> Thor)
  -> rcu_udp_bridge.py
  -> /motor_can_feedback + /imu0 + /imu1
  -> motor_feedback_listener.py + robot_observation_bridge.py
  -> /robot_observation
  -> thor_policy_runner.py
```

## Canonical Files

- `Software/src/motor_control/motor_control/bridges/rcu_udp_bridge.py`
- `Software/src/motor_control/launch/rl_robot_launch.py`
- `Software/src/motor_control/launch/rcu_launch.py`
- `Charlie/STM32Cube/Tools/ROS2/HANDOVER_INSTRUCTIONS.md`

## Network Defaults

- `rcu_ip`: `192.168.100.10`
- Thor host IP: `192.168.100.20/24`
- Telemetry input port: `7700`
- Command output port: `7701`
- Supervision output port: `7702`

## Build and Launch

```bash
source /opt/ros/jazzy/setup.bash
cd Software
colcon build --packages-select motor_control
source install/setup.bash

# Full RL-to-hardware pipeline
ros2 launch motor_control rl_robot_launch.py

# RCU bridge + observation only
ros2 launch motor_control rcu_launch.py
```

## Safety Services

```bash
# Enable motors
ros2 service call /rcu_motor_estop std_srvs/srv/SetBool "{data: true}"

# Full e-stop (disable motors + assert PDU fault)
ros2 service call /rcu_motor_estop std_srvs/srv/SetBool "{data: false}"

# Clear PDU fault
ros2 service call /rcu_pdu_fault std_srvs/srv/SetBool "{data: false}"
```

## Notes

- This document supersedes previous serial bridge instructions in `Software/`.
- For protocol-level packet details, use the handover file in `Charlie/STM32Cube/Tools/ROS2/`.

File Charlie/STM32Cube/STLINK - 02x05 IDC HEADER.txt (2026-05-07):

STLINK - 02x05 IDC HEADER:
1 - 3.3V - RED
2 - SWDIO - YELLOW
3 - GND - BLACK
4 - SWCLK - GREEN
5 - GND - BLACK
6 - SWO - BLUE
7 - UART_RX - BROWN
8 - UART_TX - GREY
9 - 5V - PURPLE
10 - NRST - WHITE

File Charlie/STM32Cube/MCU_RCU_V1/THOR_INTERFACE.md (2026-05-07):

# RCU UDP Interface — Thor Integration Notes

## Network Configuration

| Parameter | Value |
|---|---|
| RCU static IP | `192.168.100.10` |
| Subnet mask | `255.255.255.0` |
| Default gateway | `192.168.100.1` |
| **Thor IP (required)** | `192.168.100.20` ← update `THOR_IP_D` in `eth_udp.c` once confirmed |
| Telem TX port (RCU→Thor) | **7700** |
| Cmd RX port (Thor→RCU) | **7701** |
| Supervision TX port (RCU→Thor) | **7702** |

---

## Packet Format

All packets share a 6-byte header, followed by a fixed payload. All
multi-byte fields are **little-endian** unless noted.

```
Offset  Size  Field
0       2     Magic = 0x5243  ('RC')
2       1     Type  (see below)
3       1     Seq   (rolling 0–255)
4       2     Len   (payload bytes, LE uint16)
6       N     Payload
```

---

## Type 0x01 — Slow Telemetry (RCU → Thor, 10 Hz)

Payload: `rcu_telem_payload_t` (see `rcu_pkt.h`)

| Field | Type | Unit | Notes |
|---|---|---|---|
| `fpga_status0` | uint8 | — | FPGA STATUS0 register |
| `fpga_fault_code` | uint8 | — | FPGA fault register |
| `fpga_state_code` | uint8 | — | 0=IDLE 1=PCHG 2=ARMED 3=COMPUTE |
| `fpga_actions` | uint8 | — | FPGA action register |
| `v_vraw_mv` | int16 | mV | Raw battery voltage |
| `v_12v_mv` | int16 | mV | 12 V rail |
| `v_24v_mv` | int16 | mV | 24 V rail |
| `i_vraw_ma` | int16 | mA | Battery current |
| `i_12v_ma` | int16 | mA | 12 V current |
| `i_24v_ma` | int16 | mA | 24 V current |
| `therm1_dc` | int16 | 0.1 °C | PDU thermistor 1 |
| `therm2_dc` | int16 | 0.1 °C | PDU thermistor 2 |
| `ssd_i_ma` | int16 | mA | SSD energy meter current |
| `ssd_v_mv` | int16 | mV | SSD energy meter voltage |
| `ssd_t_dc` | int16 | 0.1 °C | SSD energy meter temperature |
| `imu0_accel[3]` | int16×3 | LSB | 0.122 mg/LSB at ±4g |
| `imu0_gyro[3]` | int16×3 | LSB | 17.5 mdps/LSB at ±500 dps |
| `imu0_temp` | int16 | — | Raw (°C = raw/256 + 25) |
| `imu1_accel[3]` | int16×3 | LSB | Same scaling as IMU0 |
| `imu1_gyro[3]` | int16×3 | LSB | Same scaling as IMU0 |
| `imu1_temp` | int16 | — | Same scaling as IMU0 |

---

## Type 0x02 — Motor Feedback (RCU → Thor, ~100 Hz)

Payload: `rcu_motor_fb_payload_t` (see `rcu_pkt.h`)

```
uint8   count        — number of valid slots (0..16)
uint8   _pad[3]
slot[0..count-1]:
  uint8   bus        — 0=right, 1=left
  uint8   motor_id   — 1..8
  uint16  pos_u16    — encoded: 0..65535 → -12.57..+12.57 rad
  uint16  vel_u16    — encoded: 0..65535 → -15..+15 rad/s
  uint16  cur_u16    — encoded: 0..65535 → -120..+120 N·m
  uint8   error_code — RS04 fault_bits from feedback frame
  uint8   _pad
```

**Decode formula** for pos/vel/torque:
```
value = min + (raw / 65535.0) * (max - min)
```

---

## Type 0x10 — Motor Command (Thor → RCU)

Payload: array of `rcu_motor_cmd_entry_t` entries.
`count = payload_len / sizeof(rcu_motor_cmd_entry_t)` (10 bytes each).

```
uint8   bus        — 0=right, 1=left
uint8   motor_id   — 1..8
uint16  pos_u16    — encoded position  (-12.57..+12.57 rad)
uint16  vel_u16    — encoded velocity  (-15..+15 rad/s)
uint16  trq_u16    — encoded torque ff (-120..+120 N·m)
uint8   kp_u8      — encoded Kp: (raw/255) * 5000
uint8   kd_u8      — encoded Kd: (raw/255) * 100
```

Motors default to **operation control mode (Type 1, RS04 private protocol)**.
Before sending motion commands, the motor must be enabled via a separate
mechanism (currently: `motor_bus_send_enable(bus, id, true, false)` called
from RCU startup or a future supervisory packet).

---

## Motor Coordinate / Scale Reference (RS04 private protocol)

| Quantity | Range | 16-bit span |
|---|---|---|
| Position | ±12.57 rad (±4π) | 0..65535 |
| Velocity | ±15 rad/s | 0..65535 |
| Torque | ±120 N·m | 0..65535 |
| Kp | 0..5000 | in command only |
| Kd | 0..100 | in command only |

---

## Bench Bring-Up Without Thor (Windows 11 PC)

Set your PC NIC to static IP `192.168.100.20/24`.  Use **Wireshark** or a
simple Python script to receive UDP on port 7700.

Minimal Python listener:
```python
import socket, struct

sock = socket.socket(socket.AF_INET, socket.SOCK_DGRAM)
sock.bind(("0.0.0.0", 7700))

while True:
    data, addr = sock.recvfrom(2048)
    magic, ptype, seq, length = struct.unpack_from("<HBBh", data, 0)
    if magic != 0x5243:
        continue
    print(f"type=0x{ptype:02X} seq={seq} len={length} from {addr}")
    # For slow telem (0x01), first int16 LE at offset 6 = fpga_status0 + fault packed
    # Use struct.unpack to parse rcu_telem_payload_t fields
```

To send a motor command from the PC:
```python
import socket, struct

HDR = struct.pack("<HBBh", 0x5243, 0x10, 0, 10)  # 1 entry = 10 bytes
# bus=0 right, motor_id=1, pos=0, vel=0, trq=0 (mid-scale=32767), kp=0, kd=0
ENTRY = struct.pack("<BBHHHBBxx", 0, 1, 32767, 32767, 32767, 0, 0)
sock = socket.socket(socket.AF_INET, socket.SOCK_DGRAM)
sock.sendto(HDR + ENTRY, ("192.168.100.10", 7701))
```

> **Note:** mid-scale (32767) on pos/vel = 0 rad / 0 rad/s.
> mid-scale on torque = 0 N·m feedforward.

---

## Interface Status

All integration items below are resolved as of handover.

- **Thor static IP** confirmed as `192.168.100.20`. `THOR_IP_D` in `eth_udp.c` is set accordingly.
- **Motor enable/disable supervisory command** is implemented as `DBGCMD_MOTOR_ENABLE` (0x0C). See §Debug Commands above.
- **Motor feedback strategy** settled as command-response: the RCU caches the last RS04 Type-2 reply per motor and re-transmits at 200 Hz via the fast telemetry loop. Active RS04 Type-24 reporting is not required.

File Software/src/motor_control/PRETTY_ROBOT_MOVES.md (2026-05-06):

# Pretty Robot Moves

Suspended-leg choreography runner for Thor. Smoothly interpolates between named
joint-space poses using cosine ease-in/ease-out PD control. No RL policy.

---

## 1. Build (run once after any code change)

```bash
cd ~/ros2_ws          # or wherever the workspace root is
colcon build --packages-select motor_control
source Software/install/setup.bash
```

---

## 2. Run

### Full launch — recommended (starts RCU bridge automatically)

```bash
ros2 launch motor_control pretty_robot_moves_launch.py
```

### With options

```bash
# Choose a sequence
ros2 launch motor_control pretty_robot_moves_launch.py sequence:=taps
ros2 launch motor_control pretty_robot_moves_launch.py sequence:=shapes
ros2 launch motor_control pretty_robot_moves_launch.py sequence:=kicks

# Adjust speed (default 0.3 — slow and safe)
ros2 launch motor_control pretty_robot_moves_launch.py speed:=0.5

# Play once then stop
ros2 launch motor_control pretty_robot_moves_launch.py no_loop:=True

# Custom RCU IP
ros2 launch motor_control pretty_robot_moves_launch.py rcu_ip:=192.168.100.10

# Combine options
ros2 launch motor_control pretty_robot_moves_launch.py sequence:=taps speed:=0.6 no_loop:=True
```

### Script only — if the RCU bridge is already running separately

```bash
ros2 run motor_control pretty_robot_moves.py
ros2 run motor_control pretty_robot_moves.py --sequence taps --speed 0.5
```

### Direct Python (no colcon build required)

```bash
cd ~/ros2_ws
source Software/install/setup.bash
python3 Software/src/motor_control/motor_control/pretty_robot_moves.py --sequence kicks
```

---

## 3. Available sequences

| Name | Description |
|---|---|
| `kicks` | Stand → extend → kick left → kick right → stand *(default)* |
| `taps` | Stand → 6 rapid alternating ankle-point taps → stand |
| `shapes` | Stand → knees up → extend → legs back → stand |

---

## 4. Keyboard controls (while running — type command then press Enter)

| Key | Action |
|-----|---|
| `q` | Safe stop — ramps back to standing then exits |
| `p` | Pause / resume |
| `n` | Skip to next move immediately |
| `l` | Toggle looping on/off |
| `+` | Increase speed by 10 % |
| `-` | Decrease speed by 10 % |

---

## 5. All launch arguments

| Argument | Default | Description |
|---|---|---|
| `sequence` | `kicks` | Which sequence to run (`kicks`, `taps`, `shapes`) |
| `speed` | `0.3` | Global speed multiplier (1.0 = as written, 0.3 = 3× slower) |
| `no_loop` | `False` | Set `True` to play once then exit |
| `rcu_ip` | `192.168.100.10` | IP address of the RCU |
| `kp_scale` | `0.20` | Stiffness gain scale (keep ≤ 0.25) |
| `kd_scale` | `1.00` | Damping gain scale |
| `loop_hz` | `66.67` | Control loop frequency (Hz) |
| `max_position_error_rad` | `0.90` | Abort threshold for joint tracking error (rad) |
| `auto_enable` | `True` | Auto-enable motors on startup |
| `device` | `cpu` | Torch device |

---

## 6. Safety

- **Soft limits** — defined in `pretty_robot_moves_joint_limits.json`.
  Any commanded position that crosses a soft limit sends **zero kp/kd/torque**
  to all motors before raising an error.
- **Warn zone** — 0.05 rad before the soft limit; a warning is printed to console.
- **Tracking error abort** — if any joint falls more than `max_position_error_rad`
  behind its target, motors are zeroed and the script exits safely.
- **Exit** — any quit path (keyboard `q`, Ctrl-C, or error) ramps back to the
  standing pose before shutting down.

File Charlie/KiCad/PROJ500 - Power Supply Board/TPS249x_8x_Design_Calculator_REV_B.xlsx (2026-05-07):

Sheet: Instructions
 | © 2016
TPS249x/8x Design Tool- Rev. B
Typical design procedure
Typical applications require multiple passes through the design tool using MOSFET factors such as transient
thermal response and safe operating area curves. Refer to the following application reports for more detail.
Robust Hot Swap Design (http://www.ti.com/lit/pdf/slva673)
The basic design process follows:
1. Enter operating conditions.
2. Select current limit parameters.
3. Enter MOSTFET SOA characteristics & power limit.
4. Select start up conditions (load and/or soft start). Check whether FET is operating with reasonable margin, within the SOA curve.
If not, try changing start-up conditions (soft start values, timer values), add more FETs in parallel, or switch to FET with better SOA.
5. Enter desired UVLO and OVLO values to get recommended resistor values.
6. Done
Notes
1. This worksheet is designed for use with Microsoft Excel 5.0 or later. Its use is intended to assist power supply designers in their
routine, day-to-day calculations.
2. All worksheets have light green inputs cells, white calculated cells, yellow warning cells and red high-risk cells.
3. Formulas and device constants used in the spreadsheet are locked to prohibit them from accidentally being overwritten or deleted.
TEXAS INSTRUMENTS TEXT FILE LICENSE Copyright (c) 2014 Texas Instruments Incorporated All rights reserved not granted herein. Limited License. Texas Instruments Incorporated grants a world-wide, royalty-free, non-exclusive license under copyrights and patents it now or hereafter owns or controls to make, have made, use, import, offer to sell and sell ("Utilize") this software subject to the terms herein. With respect to the foregoing patent license, such license is granted solely to the extent that any such patent is necessary to Utilize the software alone. The patent license shall not apply to any combinations which include this software, other than combinations with devices manufactured by or for TI (“TI Devices”). No hardware patent is licensed hereunder. Redistributions must preserve existing copyright notices and reproduce this license (including the above copyright notice and the disclaimer and (if applicable) source code license limitations below) in the documentation and/or other materials provided with the distribution Redistribution and use in binary form, without modification, are permitted provided that the following conditions are met: * No reverse engineering, decompilation, or disassembly of this software is permitted with respect to any software provided in binary form. * any redistribution and use are licensed by TI for use only with TI Devices. * Nothing shall obligate TI to provide you with source code for the software licensed and provided to you in obje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

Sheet: Design Calculator
TPS2490/1/2/3 & TPS2480/1/2/3 Hot Swap Design Tool
 | www.ti.com/hotswap
 |  |  | Enter Values in Green Shaded Cells
 |  |  | Calculated Values are shown in White Cells
 |  |  | Yellow and Red cells highlight pottential issues with the design. Red highlights items that are higher risk.
 | Step 0: Calculator Tutorials |  | Note: Before proceeding, please watch the video tutorials listed to ensure accurate results from this tool!
 |  |  | Steps 1 & 2: Operating Conditions, Current Limit, & Circuit Breaker (7:41) (https://training.ti.com/node/1133677)
 |  |  | Step 3: MOSFET Selection (9:58) (https://training.ti.com/node/1133673)
 |  |  | Step 4: Startup (10:32) (https://training.ti.com/node/1133664)
 |  |  | Step 5: UVLO, OVLO & PGD Thresholds (4:20) (https://training.ti.com/node/1133681)
 |  |  | TPS2490 Datasheet (http://www.ti.com/product/TPS2490)
 |  |  | I understand and agree to watch the video tutorials if help is needed. (Choose Yes to enable the calculator.) |  |  | Yes
 |  |  | Assure to follow the layout and application guidelines listed on the datasheet. |  |  | Yes
 |  |  | *For additional questions not addressed in the videos, please post on E2E.ti.com
 | Step 1: Operating Conditions |  |  | Minimum Input Operating Voltage: VIN(MIN) | 20 | V
 |  |  |  | Nominal Input Operating Voltage: VIN(NOM) | 48 | V
 |  |  |  | Maximum Input Operating Voltage: VIN(MAX) | 60 | V
 |  |  |  | Maximum Load Current: IOUT(MAX) | 15 | A
 |  |  |  | Maximum Output Load Capacitance: CLOAD | 500 | µF
 |  |  |  | Maximum Ambient Operating Temperature: TMAX | 65 | oC
 | Steps 1 & 2: Operating Conditions, Current Limit, & Circuit Breaker (https://training.ti.com/node/1133677)
 | Step 2: Current Limit and Circuit Breaker |  |  | Maximum Recommended Value for Rs | 2.97 | mW
 |  |  |  | Use External Resistor Divider to Reduce Effecitve RS | No
 |  |  |  | Enter the Resistance for RS | 2 | mW
 |  |  |  | Recommended Value for RCL1 | NA | W
 |  |  |  | Recommended Value for RCL2 | NA | W
 |  |  |  | Enter value for RCL1 | 10 | W
 |  |  |  | Enter value for RCL2 | 2 | W
 | Steps 1 & 2: Operating Conditions, Current Limit, & Circuit Breaker (https://training.ti.com/node/1133677) |  |  | Effective Sense Resistance (RS,EFF) | 2.00 | mW
 |  |  |  | Resulting Minimum Current Limit | 22.5 | A
 |  |  |  | Resulting Typical Current Limit | 25.0 | A
 |  |  |  | Resulting Maximum Current Limit | 27.5 | A
 |  |  |  | Maximum Power Dissipation in RS | 1.5 | W
 | Step 3: MOSFET Selection |  |  | Q1 FET Name | IPB042N10N3GATMA1
 |  |  |  | Estimated MOSFET RQJA | 30 | oC/W
 |  |  |  | Number of MosFETs | 1 | #
 |  |  |  | MOSFET On resistance @ TJ,DC | 4.2 | mW
 |  |  |  | Maximum FET Junction Temperature | 150 | oC
 |  |  |  | 100ms SOA Current (re-use 1ms data if unavailable) @ VIN(MAX) | 40.0 | A
 |  |  |  | 1ms SOA Current @ VIN(MAX) | 5.0 | A
 | Step 3: MOSFET Selection (https://training.ti.com/node/1133673) |  |  | 10ms SOA Current @ VIN(MAX) | 1.0 | A
 |  |  |  | 100ms Current at @ VIN(MAX) (use DC if 100ms not available) | 0.4 | A
 |  |  |  | 1s or DC SOA Current at @ VIN(MAX) (use DC if 1s not available) | 0.4 | A
 |  |  |  | FET Power dissapation at full load (per FET) | 0.9 | W
 | Note: TI recommends choosing a FET with SOA current specified for 100ms and/or 1s or DC. If choosing a FET without these parameters, this calculator will estimate the values via extrapolation, which leaves an inherent associated risk. |  |  | Maximum steady state FET Junction Temperature (TJ,DC) | 93.3 | oC
 |  |  |  | Minimum Power Limit to Ensure Vsns > 5mV & Vprog > 0.4V (PLIM,MIN) | 150.0 | W
 |  |  |  | Target Power Limit | 149.0 | W
 |  |  |  | Select R3 | 51.0 | kW
 |  |  |  | Calculated R4 | 8.93 | kW
 |  |  |  | Actual R4 (Select next available std. value) | 10 | kW | Note: Hover here to see the 3 values affecting this curve, consult a thermal expert if you are unsure!
 |  |  |  | Actual PLIM | 163.93 | W
 | Step 4: Startup |  |  | Load Turn-On Threshold | 0 | V
 |  |  |  | Startup Load Type | Constant Current
 |  |  |  | Startup Load Value | 0 | A |  |  |  |  | tON | 0.00555557377
 |  |  |  | Use External Soft-Start Control | Yes
 |  |  |  | Typical Start Time with Vinmax (Tstart) | 272.73 | ms |  |  |  |  | ISOURCE(MAX) | 3.6e-05
 |  |  |  | IFET - ILOAD margin (lowest for Vout range) | 100% |  |  |  |  |  | VTMR_TH(MAX) | 4.1
 |  |  |  | Target Fault Timer: Tstart + Margin | 477.27 | ms |  |  |  |  | CO-TOL | 0.2
 |  |  |  | Target Timer capacitance | 2982.95 | nF |  |  |  |  | CT_TOL | 0.2
 |  |  |  | Selected Timer capacitance | 100 | nF
 | Step 4: Startup (https://training.ti.com/node/1133664) |  |  | Final Fault Timer(Tfault) | 16.00 | ms |  |  |  |  | CT | 6.829290684e-08
 |  |  |  | Derated SOA / PLIM | 1.48 |  |  |  |  |  | CT(nF) | 68.29290684
 |  |  |  | Can a "hot" board be hotplugged | No
 |  |  |  | Recommended slew Rate (max) | 0.50 | V/ms
 |  |  |  | Recommended slew Rate (min) | 0.09 | V/ms
 | Note: This is the typical dv/dt rate, but max value can be larger. This is because the gate source current can vary from 16uA to 28uA. Thus TI recommends keeping the overall SOA margin during start-up >1.5 in order to compensate for this. |  |  | dv/dt rate on Vout | 0.15 | V/ms
 |  |  |  | calculated SS capacitance | 146.67 | nF
 |  |  |  | actual SS capacitance | 100 | nF
 |  |  |  | actual dv/dt rate on Vout | 0.22 | V/ms
 |  |  |  | SOA margin during start-up | 2.47
 |  |  |  | Target Fault Time | 1 | ms
 |  |  |  | Calculated Timer Capacitance | 6.25 | nF
 |  |  |  | Actual Timer Capacitance (pick one smaller than CT,CALC) | 3.3 | nF
 |  |  |  | Actual Fault Time (Tfault) | 0.53 | ms
 |  |  |  | SOA margin during "hot-short" or "start-into short" | 1.48
 | Step 5: UVLO, OVLO & PGD Thresholds |  |  | Target Under - Voltage | 20 | V |  |  |  |  | VOV | 68.9 | 69.255
 |  |  |  | Recommended R2 | 10.00 | kW |  |  |  |  | VOV_H | 1.35
 |  |  |  | Actual R2 | 10 | kW |  |  |  |  | VUV | 15 | 14.9127907
 |  |  |  | Calculated R1 | 138.15 | kW |  |  |  |  | VUV_H | 1.35
 |  |  |  | Actual R1 | 150 | kW |  |  |  |  | VUVEN_H | 1.25
 |  | Resulting Thresholds: | Minimum | Typical | Maximum |  |  |  |  |  | R3(k) | 1
 | Step 5: UVLO, OVLO & PGD Thresholds (https://training.ti.com/node/1133681) | Resulting Upper UVLO Threshold = | 21.12 | 21.60 | 22.08 | V
 |  | Resulting Lower UVLO Threshold = | 19.52 | 20.00 | 20.48 | V |  |  |  |  | R1+R2 | 50.04
 |  |  |  |  |  |  |  |  |  |  | R2+R3 | 4.25
 |  |  |  |  |  |  |  |  |  |  | R2(k) | 3.25
 | Design Summary |  |  | RS = | 2 | mW |  |  |  |  | R1(k) | 46.78
 |  |  |  | RCL1 = | DNP | W
 |  |  |  | RCL2 = | short | W |  |  |  |  | x10:
 |  |  |  | R1 = | 150 | kW |  |  | Typical | Units
 |  |  |  | R2 = | 10 | kW |  | Current limit | 25.0 | A | R1(kohm) | 467.84 | 470
 |  |  |  | R3 = | 51.0 | kW |  | Power Limit | 163.9344262 | W | R2(kohm) | 32.53 | 33
 |  |  |  | R4 = | 10 | kW |  | Fault Timeout | 0.528 | ms | R3(kohm) | 10.00 | 10
 |  |  |  | CT = | 3.30 | nF |  | Upper UVLO Threshold | 21.6 | V
 |  |  |  | C1 = | 0.10 | µF |  | Lower UVLO Threshold | 20.0 | V
 |  |  |  | Q1 = | IPB042N10N3GATMA1
 |  |  |  | RG = | 1 | kW
 |  |  |  | CG = | 100 | nF
 | Notes: | 1. Although not mandatory, CIN provides transient suppression at the VIN pin
 |  | 2. A TVS clamp from VIN to GND is absolutely mandatory to clamp the voltage overshoot upon MOSFET turn-off, e.g. during circuit breaker
 |  | 3. Componet tolerances not accounted for in Min/Max Calculations.

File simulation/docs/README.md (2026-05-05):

# Simulation & Reinforcement Learning

This directory contains all simulation and reinforcement learning work for the humanoid robot project.

The simulation environment is built using NVIDIA Isaac Sim and is used to:
- Model the humanoid robot and its sensors
- Simulate walking on flat and difficult terrain
- Train reinforcement learning policies for bipedal locomotion
- Support sim-to-real transfer onto the physical robot

All detailed documentation is maintained in Notion to support rapid iteration and collaborative development.  
This repository provides a stable and version-controlled entry point.

## Repository Structure
- `isaac/` – Robot models, assets, environments, and simulation scripts
- `rl/` – Reinforcement learning environments, training code, and policies
- `docs/` – Links to authoritative documentation hosted in Notion
- `logs/` – Training logs and evaluation outputs (not version controlled)

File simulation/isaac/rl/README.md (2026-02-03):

# Reinforcement Learning

This directory contains the reinforcement learning framework used to train
bipedal locomotion policies for the humanoid robot.

The RL system interfaces with the simulation environment and is designed to
support iterative reward shaping, curriculum learning, and sim-to-real
transfer.

## Scope
- Environment definition
- Observation and action spaces
- Reward functions
- Training and evaluation pipelines
- Policy export for deployment

## Notion Documentation

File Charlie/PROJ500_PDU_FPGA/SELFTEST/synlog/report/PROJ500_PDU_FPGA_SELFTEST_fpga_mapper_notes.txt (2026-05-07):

@N: MF916 |Option synthesis_strategy=base is enabled. 
@N: MF248 |Running in 64-bit mode.
@N: MF666 |Clock conversion enabled. (Command "set_option -fix_gated_and_generated_clocks 1" in the project file.)
@N: FX164 |The option to pack registers in the IOB has not been specified. Please set syn_useioff attribute.  
@N: FX1056 |Writing EDF file: C:\Users\charl\Documents\TEMP BACKUPS\17.03.26\PROJ500 (Humanoid)\FPGA\PROJ500_PDU_FPGA\SELFTEST\PROJ500_PDU_FPGA_SELFTEST.edi
@N: BW106 |Synplicity Constraint File capacitance units using default value of 1pF 
@N: MT320 |This timing report is an estimate of place and route data. For final timing results, use the FPGA vendor place and route report.
@N: MT322 |Clock constraints include only register-to-register paths associated with each individual clock.

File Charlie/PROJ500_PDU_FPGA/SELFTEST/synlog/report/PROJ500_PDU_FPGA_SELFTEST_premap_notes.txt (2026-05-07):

@N: MF916 |Option synthesis_strategy=base is enabled. 
@N: MF248 |Running in 64-bit mode.
@N: MF666 |Clock conversion enabled. (Command "set_option -fix_gated_and_generated_clocks 1" in the project file.)
@N: FX1184 |Applying syn_allowed_resources blockrams=2 on top level netlist pdu_selftest_mxo2 
@N: FX1143 |Skipping assigning INTERNAL_VREF to iobanks, because the table of mapping from pin to iobank is not initialized.

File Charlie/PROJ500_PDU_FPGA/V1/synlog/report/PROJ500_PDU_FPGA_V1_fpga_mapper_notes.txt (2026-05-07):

@N: MF916 |Option synthesis_strategy=base is enabled. 
@N: MF248 |Running in 64-bit mode.
@N: MF666 |Clock conversion enabled. (Command "set_option -fix_gated_and_generated_clocks 1" in the project file.)
@N: MO231 :"c:\users\charl\documents\temp backups\17.03.26\proj500 (humanoid)\fpga\proj500_pdu_fpga\pdu_glue_mxo2.sv":692:4:692:12|Found counter in view:work.pdu_glue(verilog) instance t_precharge[12:0] 
@N: FX493 |Applying initial value "0" on instance estop_ff[0].
@N: FX493 |Applying initial value "0" on instance estop_ff[1].
@N: FX493 |Applying initial value "0" on instance fb_closed_ff[0].
@N: FX493 |Applying initial value "0" on instance fb_closed_ff[1].
@N: FX493 |Applying initial value "0" on instance mcu_alive_ff[0].
@N: FX493 |Applying initial value "0" on instance mcu_alive_ff[1].
@N: FX493 |Applying initial value "0" on instance mcu_arm_ff[0].
@N: FX493 |Applying initial value "0" on instance mcu_arm_ff[1].
@N: FX493 |Applying initial value "0" on instance mcu_fault_ff[0].
@N: FX493 |Applying initial value "0" on instance mcu_fault_ff[1].
@N: FX493 |Applying initial value "0" on instance ov_ff[0].
@N: FX493 |Applying initial value "0" on instance ov_ff[1].
@N: FX493 |Applying initial value "0" on instance pchgok_ff[0].
@N: FX493 |Applying initial value "0" on instance pchgok_ff[1].
@N: FX493 |Applying initial value "0" on instance sw_arm_ff[0].
@N: FX493 |Applying initial value "0" on instance sw_arm_ff[1].
@N: FX493 |Applying initial value "0" on instance sw_compute_ff[0].
@N: FX493 |Applying initial value "0" on instance sw_compute_ff[1].
@N: FX493 |Applying initial value "0" on instance sw_rarm_ff[0].
@N: FX493 |Applying initial value "0" on instance sw_rarm_ff[1].
@N: FX493 |Applying initial value "0" on instance sw_rdisarm_ff[0].
@N: FX493 |Applying initial value "0" on instance sw_rdisarm_ff[1].
@N: FX493 |Applying initial value "0" on instance sw_rst_ff[0].
@N: FX493 |Applying initial value "0" on instance sw_rst_ff[1].
@N: FX493 |Applying initial value "0" on instance uv_ff[0].
@N: FX493 |Applying initial value "0" on instance uv_ff[1].
@N: FX493 |Applying initial value "0" on instance vbusov_ff[0].
@N: FX493 |Applying initial value "0" on instance vbusov_ff[1].
@N: FX493 |Applying initial value "0" on instance tick_1ms.
@N: FX493 |Applying initial value "1" on instance wb_rst_ms[0].
@N: FX493 |Applying initial value "0" on instance wb_rst_ms[1].
@N: FX493 |Applying initial value "1" on instance wb_rst_ms[2].
@N: FX493 |Applying initial value "0" on instance t_ksel_blank[0].
@N: FX493 |Applying initial value "0" on instance t_ksel_blank[1].
@N: FX493 |Applying initial value "0" on instance t_ksel_blank[2].
@N: FX493 |Applying initial value "0" on instance t_ksel_blank[3].
@N: FX493 |Applying initial value "0" on instance t_ksel_blank[4].
@N: FX493 |Applying initial value "0" on instance t_prechg_abort[0].
@N: FX493 |Applying initial value "0" on instance t_prechg_abort[1].
@N: FX493 |Applying initial value "0" on instance t_prechg_abort[2].
@N: FX493 |Applying initial value "0" on instance t_prechg_abort[3].
@N: FX493 |Applying initial value "0" on instance t_prechg_abort[4].
@N: FX493 |Applying initial value "0" on instance t_prechg_abort[5].
@N: FX493 |Applying initial value "0" on instance t_prechg_abort[6].
@N: FX493 |Applying initial value "0" on instance t_prechg_abort[7].
@N: FX493 |Applying initial value "0" on instance t_prechg_abort[8].
@N: FX493 |Applying initial value "0" on instance t_prechg_abort_min[0].
@N: FX493 |Applying initial value "0" on instance t_prechg_abort_min[1].
@N: FX493 |Applying initial value "0" on instance t_prechg_abort_min[2].
@N: FX493 |Applying initial value "0" on instance t_prechg_abort_min[3].
@N: FX493 |Applying initial value "0" on instance t_prechg_abort_min[4].
@N: FX493 |Applying initial value "0" on instance t_prechg_abort_min[5].
@N: FX493 |Applying initial value "0" on instance t_prechg_abort_min[6].
@N: FX493 |Applying initial value "1" on instance i2c_state[0].
@N: FX493 |Applying initial value "0" on instance i2c_state[1].
@N: FX493 |Applying initial value "0" on instance i2c_state[2].
@N: FX493 |Applying initial value "0" on instance i2c_state[3].
@N: FX493 |Applying initial value "0" on instance i2c_state[4].
@N: FX493 |Applying initial value "0" on instance i2c_state[5].
@N: FX493 |Applying initial value "0" on instance i2c_state[6].
@N: FX493 |Applying initial value "0" on instance ov_cnt[0].
@N: FX493 |Applying initial value "0" on instance ov_cnt[1].
@N: FX493 |Applying initial value "0" on instance pchgok_cnt[0].
@N: FX493 |Applying initial value "0" on instance pchgok_cnt[1].
@N: FX493 |Applying initial value "0" on instance uv_cnt[0].
@N: FX493 |Applying initial value "0" on instance uv_cnt[1].
@N: FX493 |Applying initial value "0" on instance vbusov_cnt[0].
@N: FX493 |Applying initial value "0" on instance vbusov_cnt[1].
@N: FX164 |The option to pack registers in the IOB has not been specified. Please set syn_useioff attribute.  
@N: FX1056 |Writing EDF file: C:\Users\charl\Documents\TEMP BACKUPS\17.03.26\PROJ500 (Humanoid)\FPGA\PROJ500_PDU_FPGA\V1\PROJ500_PDU_FPGA_V1.edi
@N: BW106 |Synplicity Constraint File capacitance units using default value of 1pF 
@N: MT615 |Found clock clk_osc with period 480.77ns 
@N: MT320 |This timing report is an estimate of place and route data. For final timing results, use the FPGA vendor place and route report.
@N: MT322 |Clock constraints include only register-to-register paths associated with each individual clock.

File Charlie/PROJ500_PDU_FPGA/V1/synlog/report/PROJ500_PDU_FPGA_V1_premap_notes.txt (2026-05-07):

@N: MF916 |Option synthesis_strategy=base is enabled. 
@N: MF248 |Running in 64-bit mode.
@N: MF666 |Clock conversion enabled. (Command "set_option -fix_gated_and_generated_clocks 1" in the project file.)
@N: FX493 |Applying initial value "00" on instance estop_ff[1:0].
@N: FX493 |Applying initial value "00" on instance fb_closed_ff[1:0].
@N: FX493 |Applying initial value "00" on instance mcu_alive_ff[1:0].
@N: FX493 |Applying initial value "00" on instance mcu_arm_ff[1:0].
@N: FX493 |Applying initial value "00" on instance mcu_fault_ff[1:0].
@N: FX493 |Applying initial value "00" on instance ov_ff[1:0].
@N: FX493 |Applying initial value "00" on instance pchgok_ff[1:0].
@N: FX493 |Applying initial value "00" on instance sw_arm_ff[1:0].
@N: FX493 |Applying initial value "00" on instance sw_compute_ff[1:0].
@N: FX493 |Applying initial value "00" on instance sw_rarm_ff[1:0].
@N: FX493 |Applying initial value "00" on instance sw_rdisarm_ff[1:0].
@N: FX493 |Applying initial value "00" on instance sw_rst_ff[1:0].
@N: FX493 |Applying initial value "00" on instance uv_ff[1:0].
@N: FX493 |Applying initial value "00" on instance vbusov_ff[1:0].
@N: FX493 |Applying initial value "0" on instance rarm_qual.
@N: FX493 |Applying initial value "0" on instance rdisarm_qual.
@N: FX493 |Applying initial value "0" on instance rst_qual.
@N: FX493 |Applying initial value "0" on instance tick_1ms.
@N: FX493 |Applying initial value "0" on instance spare_heartbeat.
@N: FX493 |Applying initial value "0" on instance rarm_prev.
@N: FX493 |Applying initial value "0" on instance rdisarm_prev.
@N: FX493 |Applying initial value "0" on instance rst_prev.
@N: FX493 |Applying initial value "0" on instance mcu_fault_prev.
@N: FX493 |Applying initial value "0" on instance ov_filt.
@N: FX493 |Applying initial value "0" on instance pchgok_filt.
@N: FX493 |Applying initial value "0" on instance uv_filt.
@N: FX493 |Applying initial value "0" on instance vbusov_filt.
@N: FX493 |Applying initial value "101" on instance wb_rst_ms[2:0].
@N: FX493 |Applying initial value "00000" on instance t_ksel_blank[4:0].
@N: FX493 |Applying initial value "000000000" on instance t_prechg_abort[8:0].
@N: FX493 |Applying initial value "0000000" on instance t_prechg_abort_min[6:0].
@N: FX493 |Applying initial value "000" on instance fault_code_r[2:0].
@N: FX493 |Applying initial value "0" on instance pchg_abort_was_fault.
@N: FX493 |Applying initial value "0" on instance fault_latch_r.
@N: FX493 |Applying initial value "0" on instance remote_arm_latch.
@N: FX493 |Applying initial value "0" on instance precharge_latch_r.
@N: FX493 |Applying initial value "000" on instance state[2:0].
@N: FX493 |Applying initial value "1" on instance i2c_state[0].
@N: FX493 |Applying initial value "0" on instance i2c_state[1].
@N: FX493 |Applying initial value "0" on instance i2c_state[2].
@N: FX493 |Applying initial value "0" on instance i2c_state[3].
@N: FX493 |Applying initial value "0" on instance i2c_state[4].
@N: FX493 |Applying initial value "0" on instance i2c_state[5].
@N: FX493 |Applying initial value "0" on instance i2c_state[6].
@N: MO225 :"c:\users\charl\documents\temp backups\17.03.26\proj500 (humanoid)\fpga\proj500_pdu_fpga\pdu_glue_mxo2.sv":960:4:960:12|There are no possible illegal states for state machine wb_state[1:0] (in view: work.pdu_glue(verilog)); safe FSM implementation is not required.
@N: FX1184 |Applying syn_allowed_resources blockrams=2 on top level netlist pdu_glue 
@N: FX1143 |Skipping assigning INTERNAL_VREF to iobanks, because the table of mapping from pin to iobank is not initialized.

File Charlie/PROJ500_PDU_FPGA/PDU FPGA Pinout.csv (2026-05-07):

#Pin Out file generated by Lattice Diamond Version 3.14.0
#Generated at Wed Apr 15 08:45:11 2026
#DEVICE=LCMXO2-640HC
#PACKAGE=QFN48
Index | Pin/Ball Function | Type | Bank | Dual Function | Differential | Pin Number | DQS | I/O Grouping
1 | PL2A | IO | 3 | - | True_OF_PL2B | 2 | - | +
2 | NC_UFMWL0 |  |  | - |  | - | - | +
3 | PL2B | IO | 3 | - | Comp_OF_PL2A | 3 | - | +
4 | PL2C | IO | 3 | PCLKT3_2 | True_OF_PL2D | 4 | - | +
5 | NC_POR |  |  | - |  | - | - | +
6 | PL2D | IO | 3 | PCLKC3_2 | Comp_OF_PL2C | 5 | - | +
7 | NC_FLASHARRAYWELL |  |  | - |  | - | - | +
8 | VCCIO3 |  | 3 | - |  | 6 | - | +
9 | GND |  |  | - |  | - | - | -
10 | PL3A | IO | 3 | - | True_OF_PL3B | 7 | - | -
11 | PL3B | IO | 3 | - | Comp_OF_PL3A | 8 | - | -
12 | NC_V5MON |  |  | - |  | - | - | -
13 | PL3C | IO | 3 | - | True_OF_PL3D | - | - | -
14 | PL3D | IO | 3 | - | Comp_OF_PL3C | - | - | -
15 | NC_V10MON |  |  | - |  | - | - | -
16 | GND |  |  | - |  | - | - | +
17 | PL5A | IO | 3 | PCLKT3_1 | True_OF_PL5B | 9 | - | +
18 | NC_VCCIO3 |  |  | - |  | - | - | +
19 | PL5B | IO | 3 | PCLKC3_1 | Comp_OF_PL5A | 10 | - | +
20 | PL5C | IO | 3 | - | True_OF_PL5D | - | - | +
21 | PL5D | IO | 3 | - | Comp_OF_PL5C | - | - | +
22 | PL6A | IO | 3 | - | True_OF_PL6B | 11 | - | +
23 | PL6B | IO | 3 | - | Comp_OF_PL6A | 12 | - | +
24 | PL6C | IO | 3 | - | True_OF_PL6D | - | - | +
25 | PL6D | IO | 3 | - | Comp_OF_PL6C | - | - | +
26 | NC_VCCINT |  |  | - |  | - | - | +
27 | PL7A | IO | 3 | PCLKT3_0 | True_OF_PL7B | - | - | +
28 | PL7B | IO | 3 | PCLKC3_0 | Comp_OF_PL7A | - | - | +
29 | NC_GND |  |  | - |  | - | - | +
30 | GND |  |  | - |  | - | - | -
31 | VCCIO3 |  | 3 | - |  | - | - | -
32 | PL7C | IO | 3 | - | True_OF_PL7D | - | - | -
33 | PL7D | IO | 3 | - | Comp_OF_PL7C | - | - | -
34 | NC_VCCIO2 |  |  | - |  | - | - | -
35 | VCCIO2 |  | 2 | - |  | 13 | - | +
36 | NC_PB4A |  |  | - |  | - | - | +
37 | PB4A | IO | 2 | CSSPIN | True_OF_PB4B | 14 | - | +
38 | PB4B | IO | 2 | - | Comp_OF_PB4A | 15 | - | +
39 | PB4C | IO | 2 | - | True_OF_PB4D | - | - | +
40 | PB4D | IO | 2 | - | Comp_OF_PB4C | - | - | +
41 | NC_PB6A |  |  | - |  | - | - | +
42 | PB6A | IO | 2 | MCLK/CCLK | True_OF_PB6B | 16 | - | +
43 | PB6B | IO | 2 | SO/SPISO | Comp_OF_PB6A | 17 | - | +
44 | NC_PB6B |  |  | - |  | - | - | +
45 | GND |  |  | - |  | - | - | -
46 | NC_PB6C |  |  | - |  | - | - | -
47 | PB6C | IO | 2 | PCLKT2_0 | True_OF_PB6D | 18 | - | -
48 | PB6D | IO | 2 | PCLKC2_0 | Comp_OF_PB6C | 19 | - | -
49 | PB10A | IO | 2 | - | True_OF_PB10B | - | - | -
50 | PB10B | IO | 2 | - | Comp_OF_PB10A | - | - | -
51 | NC_PB10C |  |  | - |  | - | - | -
52 | PB10C | IO | 2 | PCLKT2_1 | True_OF_PB10D | 20 | - | -
53 | PB10D | IO | 2 | PCLKC2_1 | Comp_OF_PB10C | 21 | - | -
54 | PB12A | IO | 2 | - | True_OF_PB12B | - | - | -
55 | PB12B | IO | 2 | - | Comp_OF_PB12A | - | - | -
56 | PB12C | IO | 2 | - | True_OF_PB12D | - | - | -
57 | PB12D | IO | 2 | - | Comp_OF_PB12C | - | - | -
58 | NC_GND |  |  | - |  | - | - | -
59 | GND |  |  | - |  | - | - | +
60 | PB14A | IO | 2 | - | True_OF_PB14B | - | - | +
61 | VCCIO2 |  | 2 | - |  | 22 | - | +
62 | PB14B | IO | 2 | - | Comp_OF_PB14A | - | - | +
63 | NC_PB14C |  |  | - |  | - | - | +
64 | PB14C | IO | 2 | SN | True_OF_PB14D | 23 | - | +
65 | NC_PB14D |  |  | - |  | - | - | +
66 | PB14D | IO | 2 | SI/SISPI | Comp_OF_PB14C | 24 | - | +
67 | NC_VCC |  |  | - |  | - | - | +
68 | VCC |  |  | - |  | 25 | - | +
69 | PR7D | IO | 1 | - | Comp_OF_PR7C | 26 | - | -
70 | NC_VCCIO1 |  |  | - |  | - | - | -
71 | PR7C | IO | 1 | - | True_OF_PR7D | 27 | - | -
72 | PR7B | IO | 1 | - | Comp_OF_PR7A | 28 | - | -
73 | PR7A | IO | 1 | - | True_OF_PR7B | 29 | - | -
74 | VCCIO1 |  | 1 | - |  | 30 | - | -
75 | NC_GND |  |  | - |  | - | - | -
76 | GND |  |  | - |  | - | - | +
77 | PR6D | IO | 1 | - | Comp_OF_PR6C | 31 | - | +
78 | PR6C | IO | 1 | - | True_OF_PR6D | 32 | - | +
79 | PR6B | IO | 1 | - | Comp_OF_PR6A | - | - | +
80 | PR6A | IO | 1 | - | True_OF_PR6B | - | - | +
81 | GND |  |  | - |  | - | - | -
82 | PR5D | IO | 1 | PCLKC1_0 | Comp_OF_PR5C | 33 | - | -
83 | PR5C | IO | 1 | PCLKT1_0 | True_OF_PR5D | 34 | - | -
84 | PR5B | IO | 1 | - | Comp_OF_PR5A | - | - | -
85 | PR5A | IO | 1 | - | True_OF_PR5B | - | - | -
86 | NC_VWLP |  |  | - |  | - | - | -
87 | PR3D | IO | 1 | - | Comp_OF_PR3C | 35 | - | -
88 | NC_NEG_HV_MON |  |  | - |  | - | - | -
89 | PR3C | IO | 1 | - | True_OF_PR3D | 36 | - | -
90 | PR3B | IO | 1 | - | Comp_OF_PR3A | - | - | -
91 | NC_POS_HV_MON |  |  | - |  | - | - | -
92 | PR3A | IO | 1 | - | True_OF_PR3B | - | - | -
93 | PR2D | IO | 1 | - | Comp_OF_PR2C | - | - | -
94 | NC_FSAFE |  |  | - |  | - | - | -
95 | PR2C | IO | 1 | - | True_OF_PR2D | - | - | -
96 | GND |  |  | - |  | - | - | +
97 | VCCIO1 |  | 1 | - |  | - | - | +
98 | NC_TEMPSENSE |  |  | - |  | - | - | +
99 | PR2B | IO | 1 | - | Comp_OF_PR2A | - | - | +
100 | PR2A | IO | 1 | - | True_OF_PR2B | - | - | +
101 | PT11D | IO | 0 | DONE | Comp_OF_PT11C | 37 | - | -
102 | NC_TEMPSENSEVSS |  |  | - |  | - | - | -
103 | PT11C | IO | 0 | INITN | True_OF_PT11D | 38 | - | -
104 | NC_SPARE2 |  |  | - |  | - | - | -
105 | PT11B | IO | 0 | - | Comp_OF_PT11A | - | - | -
106 | PT11A | IO | 0 | - | True_OF_PT11B | - | - | -
107 | NC_GND |  |  | - |  | - | - | -
108 | GND |  |  | - |  | - | - | +
109 | VCCIO0 |  | 0 | - |  | 39 | - | +
110 | NC_PT10D |  |  | - |  | - | - | +
111 | PT10D | IO | 0 | PROGRAMN | Comp_OF_PT10C | 40 | - | +
112 | PT10C | IO | 0 | JTAGENB | True_OF_PT10D | 41 | - | +
113 | NC_PT10C |  |  | - |  | - | - | +
114 | PT10B | IO | 0 | - | Comp_OF_PT10A | - | - | +
115 | PT10A | IO | 0 | - | True_OF_PT10B | - | - | +
116 | NC_PT9D |  |  | - |  | - | - | +
117 | PT9D | IO | 0 | SDA/PCLKC0_0 | Comp_OF_PT9C | 42 | - | +
118 | PT9C | IO | 0 | SCL/PCLKT0_0 | True_OF_PT9D | 43 | - | +
119 | NC_PT9C |  |  | - |  | - | - | +
120 | PT9B | IO | 0 | PCLKC0_1 | Comp_OF_PT9A | - | - | +
121 | PT9A | IO | 0 | PCLKT0_1 | True_OF_PT9B | - | - | +
122 | NC |  |  | - |  | - | - | +
123 | NC |  |  | - |  | - | - | +
124 | NC_PT7D |  |  | - |  | - | - | +
125 | PT7D | IO | 0 | TMS | Comp_OF_PT7C | 44 | - | +
126 | PT7C | IO | 0 | TCK | True_OF_PT7D | 45 | - | +
127 | NC_PT7C |  |  | - |  | - | - | +
128 | GND |  |  | - |  | - | - | -
129 | NC_VCCIO0 |  |  | - |  | - | - | -
130 | VCCIO0 |  | 0 | - |  | 46 | - | -
131 | PT7B | IO | 0 | TDI | Comp_OF_PT7A | 47 | - | -
132 | NC_PT7B |  |  | - |  | - | - | -
133 | PT7A | IO | 0 | TDO | True_OF_PT7B | 48 | - | -
134 | NC_PT7A |  |  | - |  | - | - | -
135 | PT6D | IO | 0 | - | Comp_OF_PT6C | - | - | -
136 | PT6C | IO | 0 | - | True_OF_PT6D | - | - | -
137 | NC_SPARE1 |  |  | - |  | - | - | -
138 | PT6B | IO | 0 | - | Comp_OF_PT6A | - | - | -
139 | PT6A | IO | 0 | - | True_OF_PT6B | - | - | -
140 | NC_VCC |  |  | - |  | - | - | -
141 | VCC |  |  | - |  | 1 | - | -
142 | NC |  | 3 | - |  | - | - | +
143 | NC |  | 1 | - |  | - | - | -
144 | NC |  | 3 | - |  | - | - | +
145 | NC |  | 3 | - |  | - | - | +
146 | NC |  | 3 | - |  | - | - | +
147 | NC |  | 3 | - |  | - | - | +
148 | NC |  | 3 | - |  | - | - | +
149 | NC |  | 3 | - |  | - | - | +
150 | NC |  | 3 | - |  | - | - | +
151 | NC |  | 2 | - |  | - | - | -
152 | NC |  | 2 | - |  | - | - | -
153 | NC |  | 2 | - |  | - | - | -
154 | NC |  | 2 | - |  | - | - | -
155 | NC |  | 2 | - |  | - | - | -
156 | NC |  | 2 | - |  | - | - | -
157 | NC |  | 2 | - |  | - | - | -
158 | NC |  | 2 | - |  | - | - | -
159 | NC |  | 2 | - |  | - | - | -
160 | NC |  | 1 | - |  | - | - | +
161 | NC |  | 1 | - |  | - | - | +
162 | NC |  | 1 | - |  | - | - | +
163 | NC |  | 1 | - |  | - | - | +
164 | NC |  | 1 | - |  | - | - | +
165 | NC |  | 1 | - |  | - | - | +
166 | NC |  | 1 | - |  | - | - | +
167 | NC |  | 1 | - |  | - | - | +
168 | NC |  | 0 | - |  | - | - | -
169 | NC |  | 0 | - |  | - | - | -
170 | NC |  | 0 | - |  | - | - | -
171 | NC |  | 0 | - |  | - | - | -
172 | NC |  | 0 | - |  | - | - | -
173 | NC |  | 0 | - |  | - | - | -
174 | NC |  | 0 | - |  | - | - | -
175 | NC |  | 0 | - |  | - | - | -

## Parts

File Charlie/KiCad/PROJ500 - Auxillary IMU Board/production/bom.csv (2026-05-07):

Designator | Footprint | Quantity | Value | LCSC Part #
C1, C2 | 0402 | 2 | 100nF/50V(10%)
C3, C4 | 0805 | 2 | 4.7uF/16V(10%)
D1 | 0805 | 1 | GR_PWR
FB1 | 0603 | 1 | 120R/3A
J1 | Molex_Micro-Fit_3.0_43045-0812_2x04_P3.00mm_Vertical | 1 | RCU
R1, R3, R4 | 0402 | 3 | 0R(10%)
R2 | 0402 | 1 | 100k(10%)
R5 | 0402 | 1 | 22R(1%)
R6 | 0402 | 1 | 1k(10%)
TP1, TP2, TP3 | TestPoint_Pad_D1.0mm | 3 | TestPoint
U1 | ST_LGA-14L_2.5x3.0mm_P0.5mm_4x3 | 1 | LSM6DSOX

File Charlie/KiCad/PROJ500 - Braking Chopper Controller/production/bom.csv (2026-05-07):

Designator | Footprint | Quantity | Value | LCSC Part #
C1, C10, C12, C7, C8 | 0402 | 5 | 0.1uF/25V(20%)
C11, C2, C9 | 0603 | 3 | 1uF/25V(20%)
C13 | CP_Radial_D12.5mm_P5.00mm | 1 | 220uF/25V(20%)
C3 | CP_Radial_D12.5mm_P5.00mm | 1 | 220uF/80V(20%)
C4 | 0603 | 1 | 1uF/100V(20%)
C5 | 0603 | 1 | 0.1uF/100V(20%)
C6 | 0402 | 1 | 10nF/25V(20%)
D1 | D_SMF | 1 | SMF14A
D2 | LED_D5.0mm | 1 | RED LED
D3 | D_SMC | 1 | SMDJ58A
D4 | LED_D5.0mm | 1 | ORANGE LED
D5 | LED_D5.0mm | 1 | GREEN LED
J1, J2, J3, J4, J6, J7 | Molex_Micro-Fit_3.0_43650-0215_1x02_P3.00mm_Vertical | 6 | MicroFit_01x02
J5 | PinHeader_1x02_P2.54mm_Vertical | 1 | 01x02_Pin_Socket
R1 | 0402 | 1 | 10R(10%)
R10 | 0402 | 1 | 7.32k(5%)
R11, R12, R13, R4, R5, R7 | 0402 | 6 | 4.7k(5%)
R14, R16 | 0402 | 2 | 10k(5%)
R15 | 0402 | 1 | 100k(5%)
R17, R3 | 0402 | 2 | 10k(10%)
R2 | 0402 | 1 | 2.2R(10%)
R6 | 0402 | 1 | 4M(5%)
R8 | 0603 | 1 | 1M(5%)
R9 | 0402 | 1 | 46.4k(5%)
RV1, RV2 | Potentiometer_Bourns_3296W_Vertical | 2 | 10K(10%)
TP1 | TestPoint_Pad_D1.5mm | 1 | GND
TP2 | TestPoint_Pad_D1.5mm | 1 | +12V
TP3 | TestPoint_Pad_D1.5mm | 1 | 2.5VREF
TP4 | TestPoint_Pad_D1.5mm | 1 | OVERTEMP
TP5 | TestPoint_Pad_D1.5mm | 1 | BUS_OV
U1 | SOT95P280X145-6N | 1 | 1EDN8511BXUSA1
U2 | TSSOP-8_4.4x3mm_P0.65mm | 1 | LM393
U3 | V48SD12005NNFA | 1 | V48SD12005NNFA
U4 | SOT-23-3 | 1 | LM4040-2.5V

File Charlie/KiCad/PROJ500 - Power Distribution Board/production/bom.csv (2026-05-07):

Designator | Footprint | Quantity | Value | LCSC Part #
BZ1 | C_Radial_D10.0mm_H12.5mm_P5.00mm | 1 | Buzzer
C1 | 0402 | 1 | 4.7nF/50V(10%)
C10, C13, C2, C21, C23, C24, C25, C26, C29, C36, C37, C38, C40, C41, C42, C45, C46, C47, C50, C51, C54, C61, C7, C8 | 0402 | 24 | 100nF/50V(10%)
C11, C12 | 0402 | 2 | 6pF/50V(10%)
C14, C18, C22, C27, C9 | 0805 | 5 | 4.7uF/16V(10%)
C15, C20, C39 | 0603 | 3 | 1uF/16V(10%)
C16, C28, C3, C4, C5, C6, C60 | 1206 | 7 | 10uF/50V(10%)
C17, C19 | 0402 | 2 | 33pF/50V(10%)
C30, C31, C32, C33, C34, C35, C55, C56, C57, C58, C59, C62 | 0402 | 12 | 10nF/50V(10%)
C43, C44, C48, C49 | 0402 | 4 | 1nF/50V(10%)
C52 | 0603 | 1 | 2.2uF/10V(10%)
C53 | 0402 | 1 | 100pF/50V(10%)
D1, D2, D3, D4 | D_SMB | 4 | SMBJ16A
D10 | 0805 | 1 | GR_MCU_LED_0
D11 | 0805 | 1 | RE_FAULT_0
D12 | 0805 | 1 | OR_MCU_LED_0
D13 | 0805 | 1 | RE_OV
D14 | 0805 | 1 | RE_FAULT_1
D15 | 0805 | 1 | OR_MOTOR
D16 | 0805 | 1 | RE_FAULT_2
D17 | 0805 | 1 | RE_FAULT
D18 | 0805 | 1 | RE_FAULT_3
D19 | 0805 | 1 | GR_K_EN
D20 | 0805 | 1 | GR_STATE_0
D21 | 0805 | 1 | OR_DBG_PWR
D22, D26, D29 | D_SMB | 3 | VSSB410S
D23 | 0805 | 1 | GR_STATE_1
D24, D27, D28 | D_SOD-123 | 3 | 14V
D25 | 0805 | 1 | GR_K_SEL
D30, D31, D32, D33, D34, D37 | D_SOD-882 | 6 | AQ3041
D35, D36 | D_SOD-123 | 2 | 3.3V
D5 | 0805 | 1 | GR_3.3V
D6 | 0805 | 1 | GR_5V
D7 | 0805 | 1 | GR_12V
D8 | 0805 | 1 | GR_5VSW
D9 | 0805 | 1 | GR_12VSW
F1, F2, F3, F4 | FUSC5141X160N | 4 | SMDH2016B260TF
F5 | RGEF500 | 1 | RGEF500
FB1 | 0603 | 1 | 120R/3A
J1 | TBP02R138102BE | 1 | AUX_OUT_3
J10, J11 | IDC-Header_2x05_P2.54mm_Vertical | 2 | IDC_02x05
J12 | Molex_Micro-Fit_3.0_43045-0400_2x02_P3.00mm_Horizontal | 1 | RS485
J13 | Molex_Micro-Fit_3.0_43045-0400_2x02_P3.00mm_Horizontal | 1 | VIN
J14 | Molex_Micro-Fit_3.0_43045-0200_2x01_P3.00mm_Horizontal | 1 | EXT_RES
J15 | Molex_Micro-Fit_3.0_43045-0400_2x02_P3.00mm_Horizontal | 1 | MOTOR_CONT
J16 | Molex_Micro-Fit_3.0_43045-0200_2x01_P3.00mm_Horizontal | 1 | THERM_1
J17 | Molex_Micro-Fit_3.0_43045-0200_2x01_P3.00mm_Horizontal | 1 | THERM_0
J18 | Molex_Micro-Fit_3.0_43045-0400_2x02_P3.00mm_Horizontal | 1 | V_SENSE
J19 | Molex_Micro-Fit_3.0_43045-0200_2x01_P3.00mm_Horizontal | 1 | ESTOP_OK
J2 | TBP02R138102BE | 1 | ESTOP_REP
J20 | Molex_Micro-Fit_3.0_43045-0600_2x03_P3.00mm_Horizontal | 1 | SW_MISC
J21 | Molex_Micro-Fit_3.0_43045-0600_2x03_P3.00mm_Horizontal | 1 | SW_REMOTE_ARM
J3 | TBP02R138102BE | 1 | AUX_OUT_2
J4 | TBP02R138102BE | 1 | AUX_OUT_1
J5 | TBP02R138102BE | 1 | AUX_OUT_0
J6 | Molex_Micro-Fit_3.0_43045-0800_2x04_P3.00mm_Horizontal | 1 | PSU_B2B_PWR
J7 | Molex_Micro-Fit_3.0_43045-0800_2x04_P3.00mm_Horizontal | 1 | PSU_B2B_SIG
J8 | Molex_Micro-Fit_3.0_43045-0800_2x04_P3.00mm_Horizontal | 1 | RCU_B2B
K1 | G5LE1A4DC12 | 1 | G5LE-1A4-DC12
K2 | G5LE-14_SPDT | 1 | G5LE-14-ASI_DC12
Q1, Q10, Q11, Q14, Q6, Q7, Q8, Q9 | SOT-23 | 8 | MMBT3904
Q12 | DMP4013LFG7 | 1 | DMP6023LFG-7
Q13 | ONSemi_SO-8FL_488AA | 1 | NTMFS5C673NLT1G
Q2, Q3, Q4, Q5 | DMP1022UFDEQ7 | 4 | DMP3014SFDE-13
R1, R100, R2, R93, R94, R99 | 0402 | 6 | 4.7k(10%)
R10, R12, R14, R16, R18, R28, R36, R43, R45, R47, R48, R49, R53, R58, R68, R7, R76, R79 | 0402 | 18 | 10k(10%)
R101, R104, R105, R108, R109, R88, R89, R92 | 0603 | 8 | 100k(1%)
R102, R55, R59 | 0402 | 3 | 330R(10%)
R103, R11, R112, R113, R114, R115, R116, R123, R13, R15, R17, R19, R22, R24, R25, R56, R57, R6, R65, R87 | 0402 | 20 | 100k(10%)
R106, R107, R75 | 0402 | 3 | 2k(1%)
R110, R117 | 0402 | 2 | 4.7R(1%)
R111 | 2512 | 1 | 10m/1W(1%)
R118, R119, R120, R121, R122, R125, R126, R128, R129, R130, R131, R132, R133, R29, R30, R31, R33, R34, R35, R39, R41, R42, R46, R5, R51, R54, R60, R61, R62, R63, R64, R67, R86, R95, R96, R97, R98 | 0402 | 37 | 1k(10%)
R124 | 0402 | 1 | 120R(1%)
R127, R69, R70, R71, R84 | 0402 | 5 | 10k(1%)
R20, R21, R23, R26, R37, R38 | 0402 | 6 | 100R(10%)
R27, R9 | 0402 | 2 | 1.8k(10%)
R3, R4 | 0402 | 2 | 60R(1%)
R32, R44, R52 | 0402 | 3 | 0R(10%)
R50 | 0402 | 1 | 3.3k(10%)
R66 | 0402 | 1 | 820(10%)
R72, R73, R90, R91 | 0402 | 4 | 2.2M(10%)
R74 | 0402 | 1 | 30k(1%)
R77, R78, R83 | 0402 | 3 | 100k(1%)
R8 | 0402 | 1 | 510R(10%)
R80, R81 | 0402 | 2 | 5.6k(1%)
R82 | 0402 | 1 | 150k(1%)
R85 | 0402 | 1 | 22k(1%)
RV1, RV2, RV3, RV4 | Potentiometer_Bourns_3296Y_Vertical | 4 | 20k(10%)
SW1 | SW_SPST_TS-1088-xR020 | 1 | SW_SPST
TH1 | 0402 | 1 | NTC/10K
TP1, TP10, TP11, TP2, TP3, TP4, TP5, TP6, TP7, TP8, TP9 | TestPoint_Pad_D1.0mm | 11 | TestPoint
U1 | SOP-4_3.8x4.1mm_P2.54mm | 1 | CPC1017N
U10 | QFN50P700X700X100-49N-D | 1 | LCMXO2-640HC-5SG48I
U11 | TSSOP-14_4.4x5mm_P0.65mm | 1 | LM339
U12, U13 | XC7WT14GT115 | 2 | 74LVC3G17GT,115
U14 | SOIC-8_3.9x4.9mm_P1.27mm | 1 | THVD1400D
U15 | SOT-363_SC-70-6 | 1 | MCP6C26T-050E_LTY
U2 | SOT-323_SC-70 | 1 | ESDCAN03-2BWY
U3 | VSON-8-1EP_3x3mm_P0.65mm_EP1.6x2.4mm | 1 | TCAN3414DRBR
U4 | SOT-23-5 | 1 | MCP1316MT-31LE/OT
U5, U8 | SOT-363_SC-70-6 | 2 | LM66100DCK
U6 | LQFP-64_10x10mm_P0.5mm | 1 | STM32G474RET6
U7 | SOT-223 | 1 | AP2114HA-3.3TRG1
U9 | TSOT-23 | 1 | LM4040-2.5V
Y1 | Crystal_DS26_D2.0mm_L6.0mm_Vertical | 1 | ECS-.327-6-13X
Y2 | ABLS8000MHZ20D3HT | 1 | ABLS-8.000MHZ

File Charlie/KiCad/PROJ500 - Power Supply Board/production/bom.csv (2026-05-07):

Designator | Footprint | Quantity | Value | LCSC Part #
C1, C102, C106, C107, C108, C111, C112, C22, C30, C33, C36, C50, C58, C63, C65, C66, C7, C77, C80, C82, C83, C9, C94, C95, C97, C98 | 0402 | 26 | 100nF/50V(10%)
C10, C100, C16, C20, C21, C25, C38, C46, C8 | 0603 | 9 | 100nF/100V(20%)
C101, C103 | 0402 | 2 | 10nF/50V(10%)
C104, C105, C85, C92 | 0603 | 4 | 1uF/16V(10%)
C109, C60, C61, C71 | 0402 | 4 | 100pF/50V(10%)
C11, C17, C18, C19, C24, C47, C48, C49, C6 | 0805 | 9 | 2.2uF/100V(10%)
C110, C64 | 0603 | 2 | 470nF/25V(10%)
C12, C13, C14, C15, C52 | 1210 | 5 | 10uF/100V(10%)
C2 | 0402 | 1 | 3.3nF/50V(10%)
C23, C34, C41, C99 | 0603 | 4 | 1uF/100V(10%)
C26, C28, C32, C70 | 0805 | 4 | 2.2uF/25V(10%)
C27, C3, C4 | CP_Radial_D10.0mm_P5.00mm | 3 | 100uF/100V(20%)
C31, C45, C72, C78, C96 | 0805 | 5 | 4.7uF/16V(10%)
C35, C39, C5, C55, C56, C62, C73, C74, C75, C76, C86, C87, C88, C89, C91 | 1206 | 15 | 10uF/50V(10%)
C37, C43 | 0402 | 2 | 4.7nF/50V(10%)
C40, C59, C69, C90 | CAPAE830X700N | 4 | 100uF/35\V(20%)
C57, C81 | 0603 | 2 | 2.2uF/10V(10%)
C67, C68, C84, C93 | 0805 | 4 | 22uF/10V(10%)
C79 | 0603 | 1 | 1uF/25V(10%)
D1, D5, D7 | D_SMC | 3 | SMC5K60A
D10 | D_SMC | 1 | SMCJ15A
D11 | D_SMB | 1 | SMBJ6.0A
D12 | 0805 | 1 | GR_12V_PGOOD
D13 | 0805 | 1 | GR_24V_SW_PGOOD
D14 | 0805 | 1 | GR_12V_SW_PGOOD
D15 | 0805 | 1 | GR_SW_PGOOD
D16 | 0805 | 1 | RED_SW_FAULT
D2 | D_SMB | 1 | VSSB410S
D3 | D_SOD-323 | 1 | Vz 10V
D4 | 0805 | 1 | OR_FAN
D6 | 0805 | 1 | OR_VRAW_PRESENT
D8 | D_SMA | 1 | SS1150-LTP
D9 | D_SMB | 1 | SMBJ26A
F1 | 65600301009 | 1 | 3x20mm/8A
F2, F5 | Fuseholder_Blade_Mini_Keystone_3568 | 2 | MINI297/10A
F3 | FUSC5141X160N | 1 | 2016L260/24MR
F4, F6 | FUSC5141X160N | 2 | 2016L300/16MR
FB1 | 1206 | 1 | 50R/12A
FB2 | 0603 | 1 | 120R/3A
J1 | AMASS_XT30PW-M_1x02_P2.50mm_Horizontal | 1 | VRAW
J10, J9 | TBP02R138102BE | 2 | 12V_SW
J11 | Molex_Micro-Fit_3.0_43045-0800_2x04_P3.00mm_Horizontal | 1 | B2B_SIG
J12 | TBP02R138102BE | 1 | 5V_SW
J2 | Molex_Micro-Fit_3.0_43045-0200_2x01_P3.00mm_Horizontal | 1 | 12V_FAN
J3 | AMASS_XT30PW-F_1x02_P2.50mm_Horizontal | 1 | VRAW_SW
J4 | TBP02R138102BE | 1 | 24V_SW
J5 | Molex_Micro-Fit_3.0_43045-0200_2x01_P3.00mm_Horizontal | 1 | EN
J6 | Molex_Micro-Fit_3.0_43045-0400_2x02_P3.00mm_Horizontal | 1 | 24V_SW
J7 | Molex_Micro-Fit_3.0_43045-0200_2x01_P3.00mm_Horizontal | 1 | 12V_SW
J8 | Molex_Micro-Fit_3.0_43045-0800_2x04_P3.00mm_Horizontal | 1 | B2B_PWR
L1 | 1008 | 1 | 1uH/5A(20%)
L2 | PA2729283NL | 1 | 28uH/9A(15%)
L3 | PA2247.223NLT | 1 | 22uH/18A(20%)
L4, L6 | ASPI-4030S | 2 | 4.7uH/3A(20%)
L5 | INDPM135125X650N | 1 | 6.8uH/11.5A(20%)
Q1 | SOT-23 | 1 | MMBT3904
Q2 | SOT-23 | 1 | 2N7002K
Q3 | SIA469DJT1GE3 | 1 | SIA469DJ
Q4 | TO-263-3_TabPin2 | 1 | IPB042N10N3G
R1, R2, R46, R58, R60, R61, R70, R71, R78, R82 | 0402 | 10 | 10k(1%)
R10 | 0805 | 1 | 100k(10%)
R11, R12, R13, R15, R19, R41, R5, R51, R7, R84, R87, R88 | 0402 | 12 | 10k(10%)
R14 | 0805 | 1 | 1k(1%)
R16 | 2512 | 1 | 3m/2W(1%)
R17, R18 | 0402 | 2 | 27k(10%)
R20 | 0402 | 1 | 100R(10%)
R21 | 0603 | 1 | 10R(1%)
R22, R36 | 0805 | 2 | 2.2R/0.125W(10%)
R23, R37 | 0603 | 2 | 100k/0.125W(1%)
R24 | 0805 | 1 | 53.6k/0.125W(1%)
R25 | 0402 | 1 | 1.3k(1%)
R26, R32 | 0402 | 2 | 62k(1%)
R27, R35 | 0603 | 2 | 2.2R/0.125W(10%)
R29 | 0402 | 1 | 205R(1%)
R3 | 0402 | 1 | 51k(1%)
R30 | 0805 | 1 | 35.7k/0.125W(1%)
R31 | 0402 | 1 | 2.4k(1%)
R33 | 0603 | 1 | 3.9k/0.125W(1%)
R34 | 0402 | 1 | 255R(1%)
R38 | 0603 | 1 | 10k/0.125W(1%)
R39, R42 | 0402 | 2 | 51k(10%)
R4 | 0402 | 1 | 33k(1%)
R43, R44, R49, R50 | 0402 | 4 | 4.7R(1%)
R45, R48 | 2512 | 2 | 5m/2W(1%)
R47, R80 | 0402 | 2 | 52.3k(1%)
R54, R59 | 0402 | 2 | 330k(10%)
R56, R89, R9, R90, R91, R92, R93 | 0402 | 7 | 1k(10%)
R57 | 0402 | 1 | 13k(1%)
R6 | 0402 | 1 | 100k(10%)
R62, R63, R68, R75, R83 | 0402 | 5 | 1K(1%)
R64, R66, R81 | 0402 | 3 | 100R(1%)
R65 | 0402 | 1 | 4.3k(1%)
R67 | 0402 | 1 | 82k(1%)
R69 | 0402 | 1 | 130K(1%)
R72 | 0402 | 1 | 2.2R(10%)
R73, R74 | 0402 | 2 | 100k(1%)
R76 | 0402 | 1 | 68K(1%)
R77, R79 | 0402 | 2 | 22R(10%)
R8 | 0805 | 1 | 470k(1%)
R85, R86 | 0402 | 2 | 150K(1%)
TH1, TH2 | 0402 | 2 | NTC/10K
TP1 | TestPoint_Pad_D1.0mm | 1 | I_VRAW_SW
TP10 | TestPoint_Pad_D1.0mm | 1 | SCL
TP11, TP6 | TestPoint_Pad_D1.0mm | 2 | 5V_SW
TP2 | TestPoint_Pad_D1.0mm | 1 | VRAW
TP3 | TestPoint_Pad_D1.0mm | 1 | VRAW_SW
TP4 | TestPoint_Pad_D1.0mm | 1 | 12V
TP5 | TestPoint_Pad_D1.0mm | 1 | 24V_SW
TP7 | TestPoint_Pad_D1.0mm | 1 | 12V_SW
TP8 | TestPoint_Pad_D1.0mm | 1 | 3.3V
TP9 | TestPoint_Pad_D1.0mm | 1 | SDA
U1 | TSSOP-14_4.4x5mm_P0.65mm | 1 | TPS2492PW
U10 | Vishay_PowerPAK_MLP44-24L | 1 | SIC437A
U11 | TSSOP-8_4.4x3mm_P0.65mm | 1 | LM393
U12 | WQFN-16-1EP_3x3mm_P0.5mm_EP1.75x1.75mm | 1 | TLA2528IRTER
U13, U6 | SOT-563 | 2 | AP62200Z6-7
U14 | XC7WT14GT115 | 1 | 74LVC3G17GT,115
U2 | SOT-363_SC-70-6 | 1 | 74LVC2G14GW
U3, U4 | VQFN32_6X6_3EP_PHA_MCH | 2 | MIC28517T-E/PHA
U5, U8 | SOT-363_SC-70-6 | 2 | MCP6C26T-050E_LTY
U7 | SOT-223 | 1 | AP2114HA-3.3TRG1
U9 | SOT-23-3 | 1 | 2.5V

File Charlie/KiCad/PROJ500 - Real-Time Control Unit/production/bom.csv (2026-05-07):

Designator | Footprint | Quantity | Value | LCSC Part #
BZ1 | C_Radial_D10.0mm_H12.5mm_P5.00mm | 1 | Buzzer
C1, C14, C19, C2, C3, C31, C33 | 0603 | 7 | 1uF/16V(10%)
C10, C11, C18, C23, C37 | 0805 | 5 | 4.7uF/16V(10%)
C12, C13, C15, C20, C21, C22, C24, C25, C27, C28, C29, C34, C35, C38, C4, C41, C5, C9 | 0402 | 18 | 100nF/50V(10%)
C16, C17 | 0402 | 2 | 6pF/50V(10%)
C26, C30 | 0603 | 2 | 2.2uF/10V(10%)
C32 | 0402 | 1 | 470pF/50V(10%)
C36 | 0402 | 1 | 22nF/50V(10%)
C39, C42, C8 | 0402 | 3 | 4.7nF/50V(10%)
C40 | 1206 | 1 | 1nF/2kV(10%)
C6, C7 | 0603 | 2 | 10uF/10V(20%)
D1 | 0805 | 1 | GR_ESP_STATUS
D2 | 0805 | 1 | GR_PWR
D3 | 0805 | 1 | GR_MCU_LED_0
D4 | 0805 | 1 | OR_MCU_LED_1
F1, F2 | FUSC4632X200N | 2 | 1.95A
FB1 | 0603 | 1 | 120R/3A
FB2 | 0402 | 1 | 220R/0.6A
J1 | USB_C_Receptacle_GCT_USB4105-xx-A_16P_TopMnt_Horizontal | 1 | USB_C_Receptacle_USB2.0_16P
J2 | Molex_Micro-Fit_3.0_43045-0800_2x04_P3.00mm_Horizontal | 1 | RCU_B2B
J4 | IDC-Header_2x08_P2.54mm_Vertical | 1 | EXPANSION_HEADER
J5 | IDC-Header_2x05_P2.54mm_Vertical | 1 | IDC_02x05
J6 | RJ45_Amphenol_RJMG1BD3B8K1ANR | 1 | RJ45_Amphenol_RJMG1BD3B8K1ANR
J7 | Molex_Micro-Fit_3.0_43045-0800_2x04_P3.00mm_Horizontal | 1 | IMU1
J8 | Molex_Micro-Fit_3.0_43045-0200_2x01_P3.00mm_Horizontal | 1 | CAN_MTR_R
J9 | Molex_Micro-Fit_3.0_43045-0200_2x01_P3.00mm_Horizontal | 1 | CAN_MTR_L
Q1 | SOT-23 | 1 | MMBT3904
R1, R17, R20, R24 | 0402 | 4 | 1k(10%)
R10, R15, R45, R48, R49, R50 | 0402 | 6 | 60R(1%)
R11, R12, R51, R52, R54 | 0402 | 5 | 22R(1%)
R13, R14, R38, R42 | 0402 | 4 | 330R(10%)
R16, R22, R23, R35, R53 | 0402 | 5 | 0R(10%)
R18, R19, R2, R25, R3, R4, R8, R9 | 0402 | 8 | 10k(10%)
R21 | 0402 | 1 | 10k(1%)
R26, R27 | 0402 | 2 | 100R(10%)
R28, R29, R30 | 0402 | 3 | 10R(10%)
R31 | 0402 | 1 | 1.5k(10%)
R32, R33, R39, R44 | 0402 | 4 | 4.7k(10%)
R34 | 0402 | 1 | 33R(10%)
R36, R43 | 1206 | 2 | 510k/500V(10%)
R37 | 0402 | 1 | 12.1k(1%)
R40, R41, R46, R47 | 0402 | 4 | 49.9R(1%)
R5, R6 | 0402 | 2 | 5.1k(1%)
R7 | 0402 | 1 | 100k(10%)
SW1 | SW_SPST_TS-1088-xR020 | 1 | ESP_BOOT
SW2 | SW_SPST_TS-1088-xR020 | 1 | SW_SPST
SW3 | SW_SPST_TS-1088-xR020 | 1 | ESP_EN
TH1 | 0402 | 1 | NTC/10K
TP1, TP2, TP3, TP4, TP5, TP6, TP7 | TestPoint_Pad_D1.0mm | 7 | TestPoint
U1, U2, U8 | SOT-363_SC-70-6 | 3 | LM66100DCK
U10 | SOT-23-5 | 1 | MCP1316MT-31LE/OT
U11 | SOT-223 | 1 | AP2114HA-3.3TRG1
U12 | LQFP-100_14x14mm_P0.5mm | 1 | STM32H723VGT6
U13, U9 | Oscillator_SMD_VSON-4_2x1.6mm | 2 | CDC6CEx
U14 | VQFN-24-1EP_4x4mm_P0.5mm_EP2.5x2.5mm | 1 | LAN8742A
U15, U16, U5 | VSON-8-1EP_3x3mm_P0.65mm_EP1.6x2.4mm | 3 | TCAN3414DRBR
U17, U18, U6 | SOT-323_SC-70 | 3 | ESDCAN03-2BWY
U3 | ESP32C3MINI1UH4X | 1 | ESP32-C3-MINI-1U-H4X
U4 | SOT-23-6 | 1 | USBLC6-2SC6
U7 | ST_LGA-14L_2.5x3.0mm_P0.5mm_4x3 | 1 | LSM6DSOX
Y1 | Crystal_DS26_D2.0mm_L6.0mm_Vertical | 1 | ECS-.327-6-13X

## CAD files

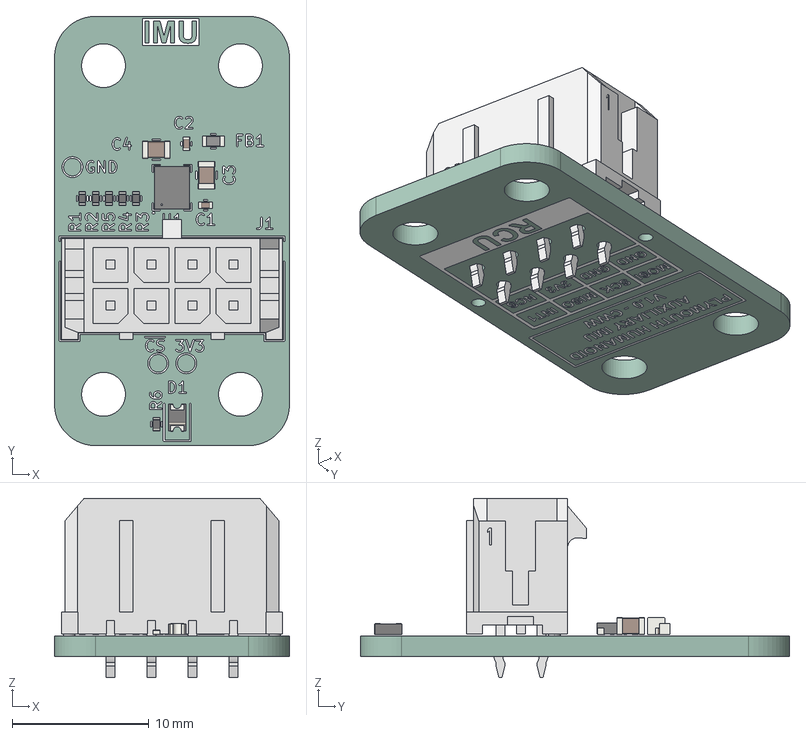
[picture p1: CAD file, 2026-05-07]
Charlie/KiCad/PROJ500 - Auxillary IMU Board/PROJ500 - Auxillary IMU Board.step
17.2 x 31.4 x 13.1 mm
R_0402_1005Metric x 6
L_0603_1608Metric
C_0402_1005Metric x 2
D_0805_2012Metric
LGA-14L
C_0805_2012Metric x 2
PROJ500 - Auxillary IMU Board_silkscreen x 2
PROJ500 - Auxillary IMU Board_PCB

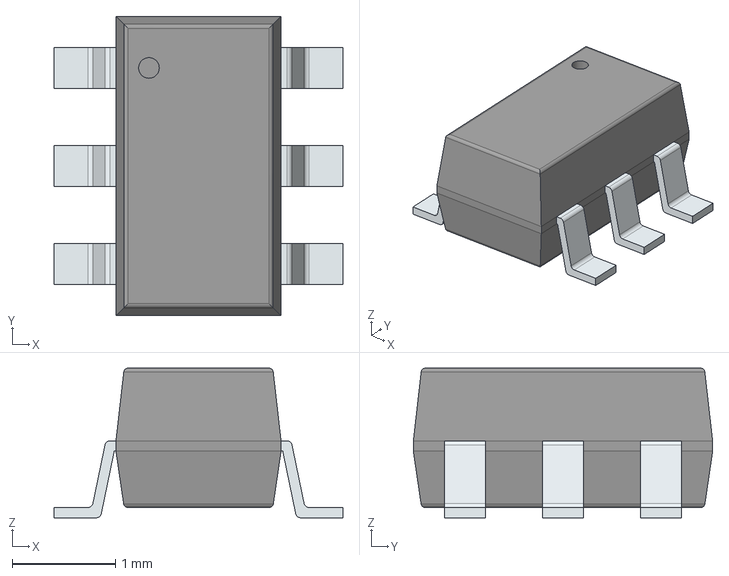
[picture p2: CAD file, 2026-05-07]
Charlie/KiCad/PROJ500 - Braking Chopper Controller/Custom Libraries, Symbols & Footprints/1EDN8511BXUSA1/3D/1EDN8511BXUSA1.stp
2.80 x 2.90 x 1.45 mm
PinsArrayLR

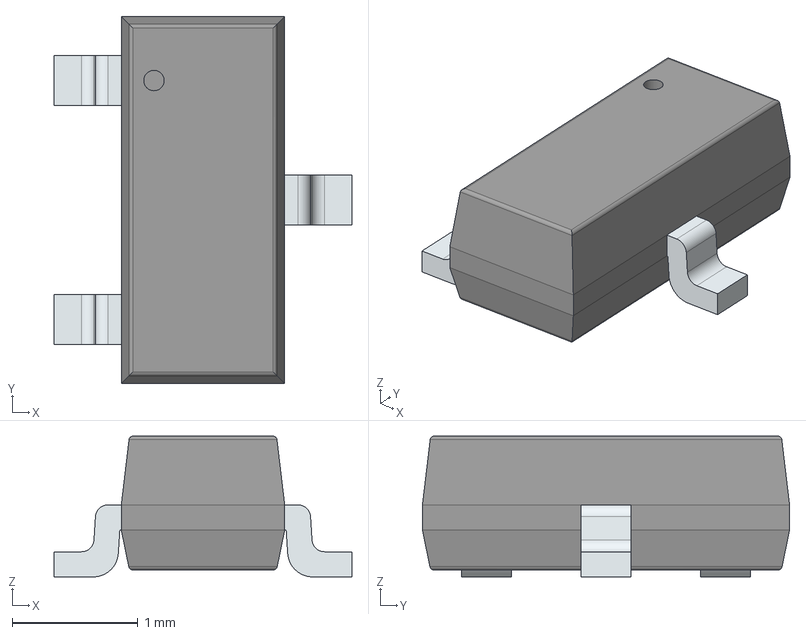
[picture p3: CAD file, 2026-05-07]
Charlie/KiCad/PROJ500 - Braking Chopper Controller/Custom Libraries, Symbols & Footprints/IRLML6344TRPBF/3D/IRLML6344TRPBF.stp
2.37 x 2.92 x 1.12 mm
PinsArrayL
FilletPinR

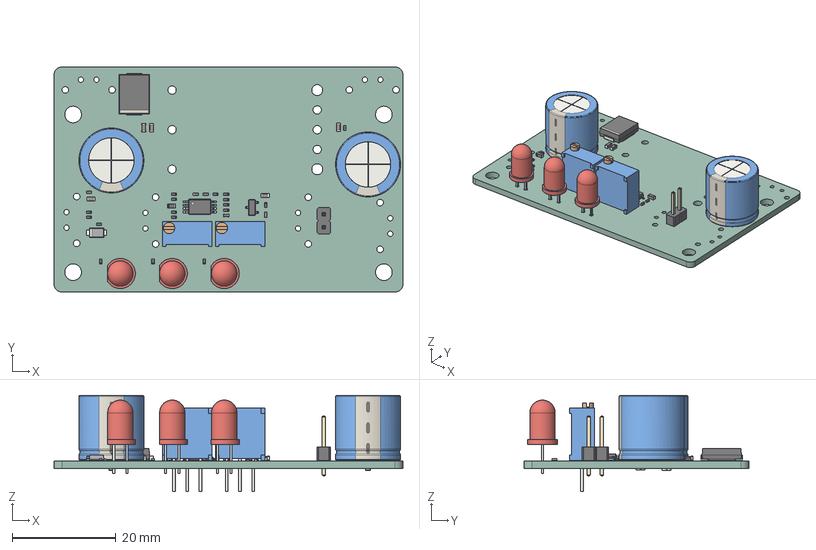
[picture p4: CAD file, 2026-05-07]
Charlie/KiCad/PROJ500 - Braking Chopper Controller/PROJ500 - Braking Chopper Controller.step
67.2 x 43.3 x 18.5 mm
C_0402_1005Metric x 6
R_0402_1005Metric x 16
C_0603_1608Metric x 5
D_SMC
TSSOP-8_4.4x3mm_P0.65mm
CP_Radial_D12.5mm_P5.00mm x 2
PinHeader_1x02_P2.54mm_Vertical
LED_D5.0mm x 3
Potentiometer_Bourns_3296W_Vertical x 2
SOT-23-3
R_0603_1608Metric
D_SMF
PROJ500 - Braking Chopper Controller_PCB

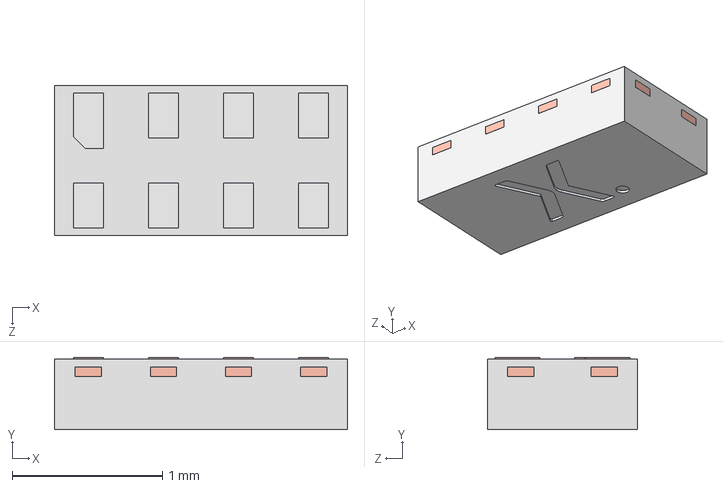
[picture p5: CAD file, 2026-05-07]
Charlie/KiCad/PROJ500 - Power Distribution Board/Custom Libraries, Symbols & Footprints/74LVC3G17GT,115/3D/74LVC3G17GT,115.stp
1.95 x 0.48 x 1.00 mm
SOT833-1 LF
SOT833-1 Mold body

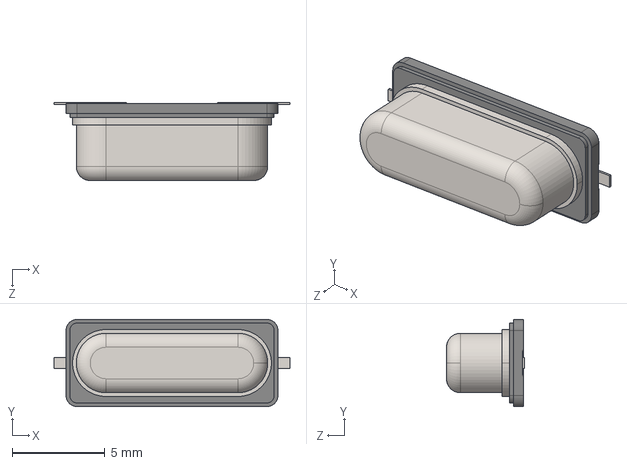
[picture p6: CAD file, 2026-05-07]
Charlie/KiCad/PROJ500 - Power Distribution Board/Custom Libraries, Symbols & Footprints/ABLS-8.000MHZ-20-D-3-H-T/3D/ABLS-8.000MHZ-20-D-3-H-T.stp
12.7 x 4.70 x 4.20 mm

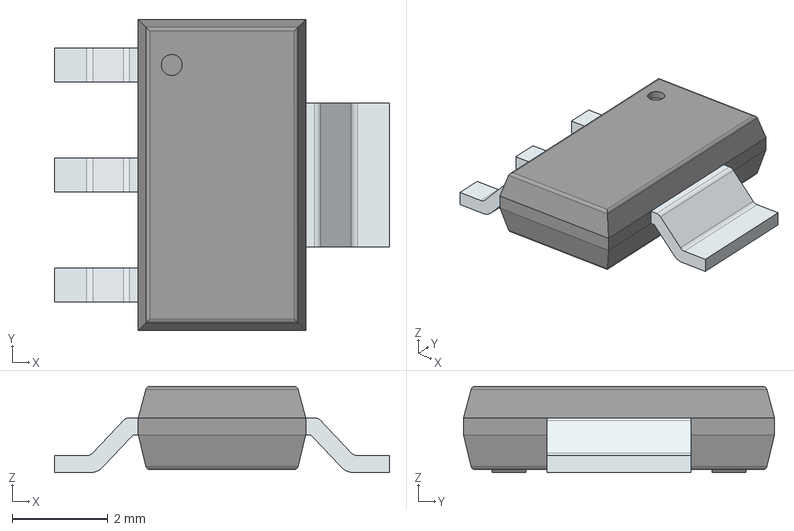
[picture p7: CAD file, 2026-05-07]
Charlie/KiCad/PROJ500 - Power Distribution Board/Custom Libraries, Symbols & Footprints/AP2114HA-3.3TRG1/3D/AP2114HA-3.3TRG1.stp
7.00 x 6.50 x 1.80 mm
PinsArrayL
FilletPinR

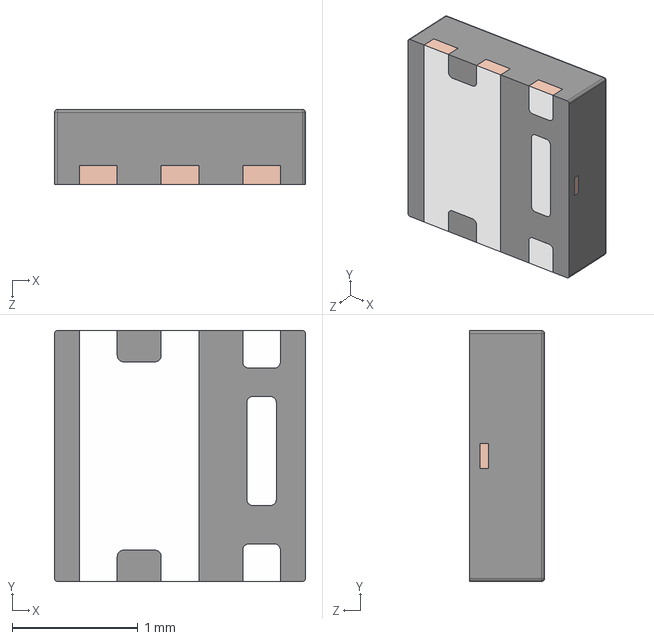
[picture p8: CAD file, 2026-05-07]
Charlie/KiCad/PROJ500 - Power Distribution Board/Custom Libraries, Symbols & Footprints/DMP3014SFDE-13/3D/DMP3014SFDE-13.stp
2.00 x 2.00 x 0.6 mm
Coumpound
LF

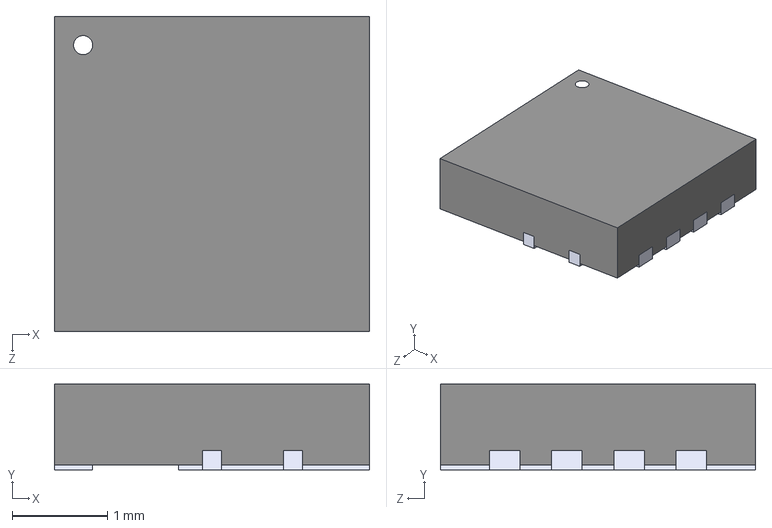
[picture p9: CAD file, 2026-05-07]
Charlie/KiCad/PROJ500 - Power Distribution Board/Custom Libraries, Symbols & Footprints/DMP6023LFG-7/3D/DMP6023LFG-7.stp
3.30 x 0.9 x 3.30 mm

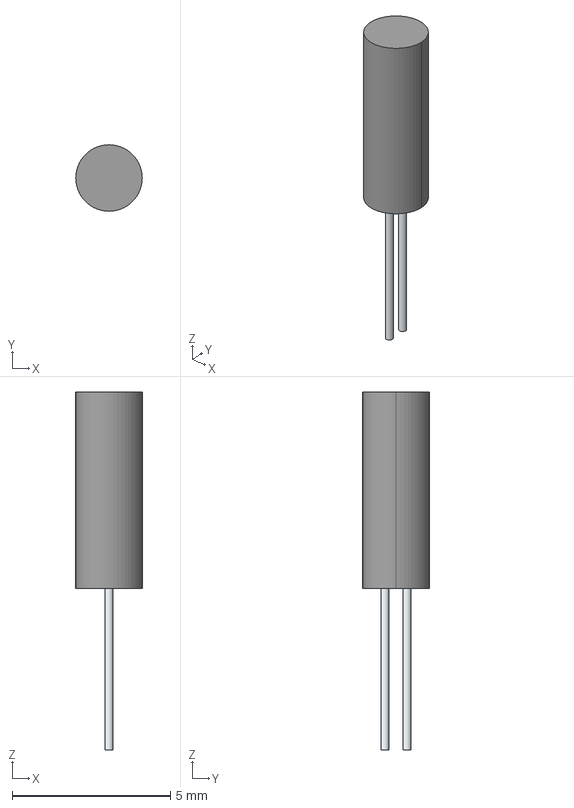
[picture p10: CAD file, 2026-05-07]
Charlie/KiCad/PROJ500 - Power Distribution Board/Custom Libraries, Symbols & Footprints/ECS-.327-6-13X/3D/ECS-.327-6-13X.stp
2.10 x 2.10 x 11.3 mm
Leads

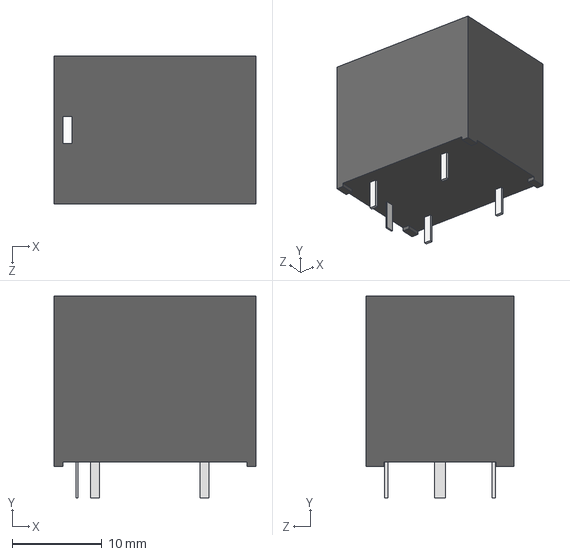
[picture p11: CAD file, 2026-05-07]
Charlie/KiCad/PROJ500 - Power Distribution Board/Custom Libraries, Symbols & Footprints/G5LE-14-ASI_DC12/3D/G5LE-14-ASI_DC12.stp
22.5 x 22.5 x 16.5 mm

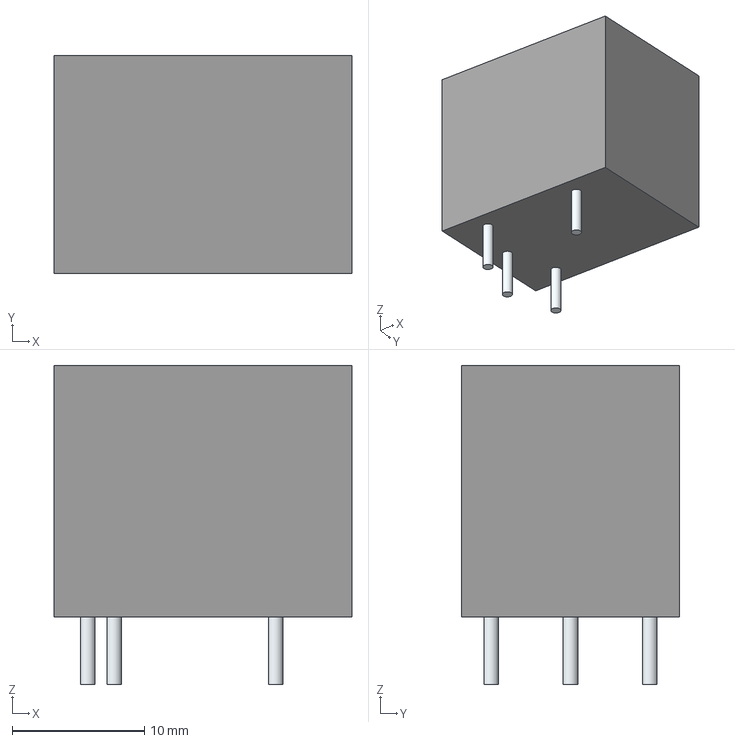
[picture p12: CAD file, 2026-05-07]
Charlie/KiCad/PROJ500 - Power Distribution Board/Custom Libraries, Symbols & Footprints/G5LE-1A4-DC12/3D/G5LE-1A4-DC12.stp
22.5 x 16.5 x 24.1 mm
Leads

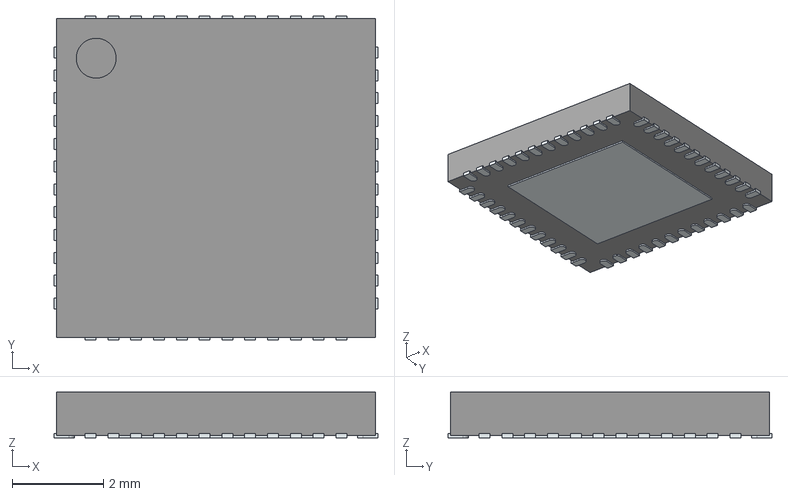
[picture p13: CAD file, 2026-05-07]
Charlie/KiCad/PROJ500 - Power Distribution Board/Custom Libraries, Symbols & Footprints/LCMXO2-640HC-5SG48I/3D/LCMXO2-640HC-5SG48I.stp
7.10 x 7.10 x 1.00 mm
ThermalPin
PinsArrayLR
PinsArrayTB

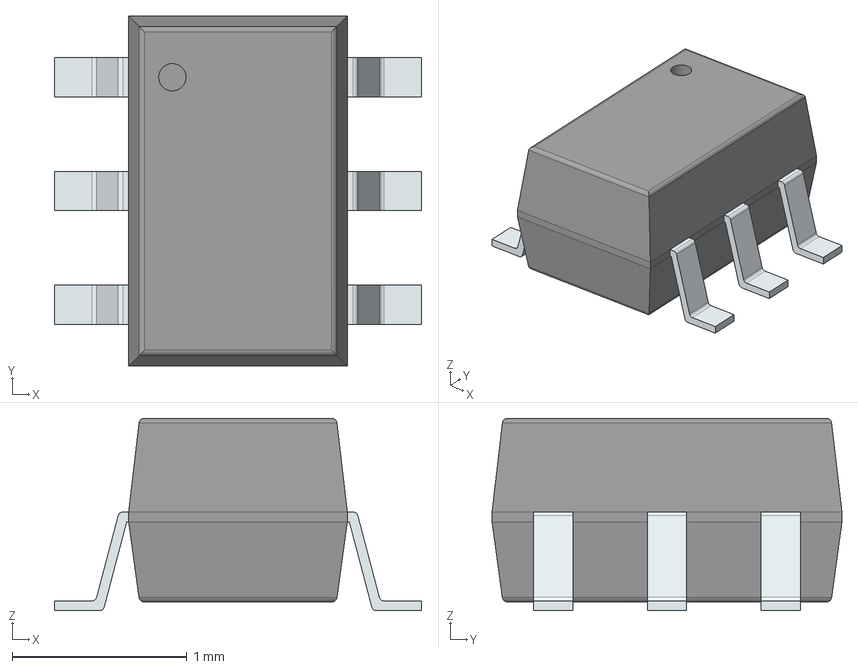
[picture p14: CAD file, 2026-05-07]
Charlie/KiCad/PROJ500 - Power Distribution Board/Custom Libraries, Symbols & Footprints/MCP6C26T-050E_LTY/3D/MCP6C26T-050E_LTY.stp
2.10 x 2.00 x 1.10 mm
PinsArrayLR

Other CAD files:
Charlie/KiCad/PROJ500 - Power Distribution Board/Custom Libraries, Symbols & Footprints/NTMFS5C673NLT1G/3D/NTMFS5C673NLT1G.stp
Charlie/KiCad/PROJ500 - Power Distribution Board/Custom Libraries, Symbols & Footprints/RGEF500/3D/RGEF500.stp
Charlie/KiCad/PROJ500 - Power Distribution Board/Custom Libraries, Symbols & Footprints/SMDH2016B260TF_24/3D/SMDH2016B260TF_24.stp
Charlie/KiCad/PROJ500 - Power Distribution Board/Custom Libraries, Symbols & Footprints/TBP02R1-381-02BE/3D/TBP02R1-381-02BE.stp
Charlie/KiCad/PROJ500 - Braking Chopper Controller/Custom Libraries, Symbols & Footprints/1EDN8511BXUSA1/Allegro/sot95p280x145-6n.psm
Charlie/KiCad/PROJ500 - Braking Chopper Controller/Custom Libraries, Symbols & Footprints/1EDN8511BXUSA1/DEHDL/1edn8511bxusa1/chips/chips.prt
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

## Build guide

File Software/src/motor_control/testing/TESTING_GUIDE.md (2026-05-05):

# Thor Motor Control — Hardware Testing Guide

Step-by-step guide for bringing up and testing the 12-motor Thor hardware stack,
from individual motor validation through to full policy deployment.

---

## 0. Connect and SSH into the Jetson

```bash
ssh jetson@192.168.100.20
```

> If the Jetson hostname is not resolved, use the IP directly.
> Default credentials depend on your setup — check with the team if unsure.

### Network check (confirm RCU is reachable)

```bash
ping -c 3 192.168.100.10
```

If ping fails, set the network interface manually:

```bash
sudo ip addr add 192.168.100.20/24 dev eth0
sudo ip link set eth0 up
ping -c 3 192.168.100.10
```

---

## 1. Pull latest code and build

```bash
cd ~/git/MEng-PROJ500-2025-26
git fetch origin
git pull origin main

source /opt/ros/jazzy/setup.bash
cd Software
colcon build --packages-select motor_control --symlink-install
source install/setup.bash
cd ..
```

> Run `source install/setup.bash` in **every new terminal** before using `ros2` commands.

---

## 2. STAGE A — Verify RCU connection (no motors commanded)

Open **one terminal**.

```bash
source /opt/ros/jazzy/setup.bash
cd ~/git/MEng-PROJ500-2025-26/Software && source install/setup.bash

ros2 launch motor_control rcu_launch.py \
    auto_enable:=False \
    active_motor_ids:="[1,2,3,4,5,6,7,8,9,10,11,12]" \
    left_bus_motor_ids:="[1,3,5,7,9,11]" \
    right_bus_motor_ids:="[2,4,6,8,10,12]" \
    scan_motor_can_ids:=True
```

**Expected output:**
- `rcu_udp_bridge ready: RCU=192.168.100.10`
- `CAN ID scan enabled`
- `OBSERVED CAN IDs` log lines listing all 12 joints once motors are powered

**Check topics in a second terminal:**

```bash
source /opt/ros/jazzy/setup.bash
cd ~/git/MEng-PROJ500-2025-26/Software && source install/setup.bash

ros2 topic list
ros2 topic hz /imu0
ros2 topic hz /motor_can_feedback
ros2 topic echo /motor_can_feedback --no-arr
```

Stop with **Ctrl+C** before proceeding.

---

## 3. STAGE B — IMU frame validation

With the RCU stack running (from Stage A or a fresh launch), the `imu_publisher`
node prints a compact one-line summary to the terminal at **4 Hz** automatically:

```
  accel [g]   x:  +0.001  y:  +0.002  z:  -1.000     gyro [r/s]  x:  +0.000  y:  +0.000  z:  +0.000
```

You can also echo the topic directly:

```bash
ros2 topic echo /imu0_remapped
```

With the robot **upright and stationary**, verify:

| Field | Expected value | Units |
|---|---|---|
| `linear_acceleration.x` | ≈ 0.0 | g |
| `linear_acceleration.y` | ≈ 0.0 | g |
| `linear_acceleration.z` | ≈ −1.0 | g |
| `angular_velocity.*` | ≈ 0.0, 0.0, 0.0 | rad/s |

> **Note:** Values are in **g-units** (not m/s²). The policy expects a unit gravity
> vector in the range [−1, 1]. `z ≈ −1.0` is correct for an upright robot.

**Tilt verification (x/y axes — do this once):**
- Tilt robot **nose down** → `accel.x` should go **negative**
- Tilt robot **right** → `accel.y` should go **negative**

If the gravity vector is wrong (e.g. on the wrong axis or wrong sign) stop and
update `imu_to_policy_frame` in `imu_publisher.py` before proceeding.

---

## 4. STAGE C — Sequential motor zero (one motor at a time)

This automatically ramps each motor to `0.0 rad` in CAN ID order (1 → 12),
holding already-zeroed motors at zero throughout.

**Terminal A — RCU stack:**

```bash
source /opt/ros/jazzy/setup.bash
cd ~/git/MEng-PROJ500-2025-26/Software && source install/setup.bash

ros2 launch motor_control rcu_launch.py \
    auto_enable:=True \
    active_motor_ids:="[1,2,3,4,5,6,7,8,9,10,11,12]" \
    left_bus_motor_ids:="[1,3,5,7,9,11]" \
    right_bus_motor_ids:="[2,4,6,8,10,12]" \
    scan_motor_can_ids:=True
```

**Terminal B — Sequential zero node:**

```bash
source /opt/ros/jazzy/setup.bash
cd ~/git/MEng-PROJ500-2025-26/Software && source install/setup.bash

ros2 run motor_control sequential_motor_zero.py
```

**Default parameters** (override with `--ros-args -p name:=value`):

| Parameter | Default | Description |
|---|---|---|
| `ramp_time_s` | `4.0` | Seconds to ramp each motor to zero |
| `hold_time_s` | `1.0` | Seconds to hold before next motor |
| `kp` | `20.0` | Position gain (Nm/rad) |
| `kd` | `1.5` | Velocity gain (Nm·s/rad) |
| `rate_hz` | `200.0` | Command publish rate |

Example with slower ramp for first test:

```bash
ros2 run motor_control sequential_motor_zero.py \
    --ros-args -p ramp_time_s:=6.0 -p kp:=15.0 -p hold_time_s:=2.0
```

**Watch each motor:**
- It should move gently to `0.0 rad` with no sudden snap
- The already-zeroed motors should remain still
- Check for any unusual sounds or resistance

Stop Terminal B with **Ctrl+C** once all 12 are confirmed at zero.
Stop Terminal A with **Ctrl+C**.

---

## 5. STAGE D — Startup ramp to standing pose (no policy)

This verifies the robot can ramp from `0.0 rad` to the standing pose and hold it.

```bash
source /opt/ros/jazzy/setup.bash
cd ~/git/MEng-PROJ500-2025-26/Software && source install/setup.bash

ros2 launch motor_control thor_12_motor_pipeline_launch.py
```

**Keyboard controls once running:**

| Key | Action |
|---|---|
| `Enter` or `p` | Advance from STANDING_HOLD to policy |
| `h` | Return to STANDING_HOLD |
| `x` or Ctrl+C | Safe exit (sends final standing pose first) |

**Expected sequence:**
1. All 12 CAN IDs appear online in the log
2. `Ros2RobotBridge ready` log line appears
3. Robot ramps to standing pose over ~8 s
4. `Startup ramp complete. Entering STANDING_HOLD.` printed
5. Robot holds the standing pose stably

**Do NOT press `p` yet** — just verify the standing hold is stable.

Stop with **`x`** or **Ctrl+C**.

---

## 6. STAGE E — Full pipeline (standing ramp → hold → policy)

Only attempt this after Stage D is confirmed stable.

```bash
source /opt/ros/jazzy/setup.bash
cd ~/git/MEng-PROJ500-2025-26/Software && source install/setup.bash

ros2 launch motor_control thor_12_motor_pipeline_launch.py
```

1. Wait for `Startup ramp complete. Entering STANDING_HOLD.`
2. Visually confirm the robot is stable in the standing pose
3. Press **`Enter`** or **`p`** to hand over to the policy
4. Monitor the `/robot_observation` topic in a second terminal:

```bash
ros2 topic echo /robot_observation
```

Stop with **`x`** or **Ctrl+C** at any time.

---

## 7. Runtime inspection (any stage)

Open a spare terminal alongside any running stage:

```bash
source /opt/ros/jazzy/setup.bash
cd ~/git/MEng-PROJ500-2025-26/Software && source install/setup.bash

# All active topics
ros2 topic list

# Message rates
ros2 topic hz /imu0
ros2 topic hz /imu0_remapped
ros2 topic hz /motor_can_feedback
ros2 topic hz /robot_observation
ros2 topic hz /robot_command

# Message content
ros2 topic echo /robot_observation
ros2 topic echo /imu0_remapped
ros2 topic echo /motor_can_feedback --no-arr

# Active nodes
ros2 node list
```

---

## 8. Emergency stop

```bash
# Software e-stop — disables all motors + clears command state (gains/torques zeroed)
ros2 service call /rcu_motor_estop std_srvs/srv/SetBool "{data: false}"

# Assert PDU fault (full power cut)
ros2 service call /rcu_pdu_fault std_srvs/srv/SetBool "{data: true}"
```

> Always have the physical e-stop within reach during any motor test.

The e-stop and a clean node shutdown (Ctrl+C) both zero all motor gains and
torques in the command cache — motors will not resume stale commands if re-enabled.

---

## 9. Troubleshooting

| Symptom | Likely cause | Fix |
|---|---|---|
| `ping 192.168.100.10` fails | Wrong subnet | Re-run `sudo ip addr add 192.168.100.20/24 dev eth0` |
| `No module named 'simulation'` | PYTHONPATH not set | Use `thor_12_motor_pipeline_launch.py` (sets PYTHONPATH automatically) |
| `Startup gate blocking TX: online=[]` | Motors not powered or CAN not connected | Check PDU, CAN cables, motor IDs |
| `Joint target exceeds policy contract joint limits` | Encoder noise at zero start | Expected — fixed in startup ramp (no limit check during ramp) |
| `TimeoutError: No RobotObservation received` | `robot_observation_bridge` not receiving IMU or feedback | Check `/imu0_remapped` and `/motor_feedback` are publishing |
| `imu_publisher` exit code 1 on shutdown | ROS2 context already shut down | Harmless — ignore |

---

## Reference

- Launch files: `Software/src/motor_control/launch/LAUNCH_FILES_GUIDE.md`
- Network and build commands: `Software/TERMINAL_COMMANDS.md`
- Startup checklist: `hardware/thor/LINUX_STARTUP_CHECKLIST.md`
- Joint limits: `simulation/isaac/configuration/joint_limits_config.json`
- Standing pose targets: `simulation/isaac/configuration/standing_pose.py`
- CAN ID → joint mapping: `Software/src/motor_control/motor_control/rcu_protocol.py`

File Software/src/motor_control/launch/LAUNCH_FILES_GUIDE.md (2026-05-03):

# motor_control Launch Files Guide

This file explains the purpose of each launch file in this folder and when to use it.

## Quick selection

- Use `rcu_launch.py` for the base RCU-to-ROS pipeline.
- Use `rl_robot_launch.py` for RL-ready full 12-motor topic wiring (runner started separately).
- Use `thor_12_motor_pipeline_launch.py` for one-command startup of both RCU stack and THOR policy runner.
- Use `rcu_bench_test_launch.py` for two-motor bench command testing.
- Use `rcu_diagnosis_launch.py` for CAN-ID bring-up/diagnosis with feedback monitoring.

## 1) rcu_launch.py

Purpose:
- Core hardware bridge pipeline for RCU communication and observation topics.

Starts:
- `rcu_udp_bridge.py`
- `motor_feedback_listener.py`
- `robot_observation_bridge.py`

Main outputs:
- `/motor_can_feedback`
- `/motor_feedback`
- `/imu0`
- `/robot_observation`

Main inputs:
- `/robot_command`

Notable defaults:
- Bench-oriented motor set by default:
  - `active_motor_ids="[1,2]"`
  - `left_bus_motor_ids="[1,2]"`
- `auto_enable=False`
- startup gate disabled by default (`wait_for_expected_online_ids=False`)

When to use:
- You want the base RCU pipeline and will provide commands from another node/tool.

Example:
```bash
ros2 launch motor_control rcu_launch.py
```

## 2) rl_robot_launch.py

Purpose:
- RL-oriented pipeline setup with full 12-motor defaults and explicit bus split.

Starts:
- `rcu_udp_bridge.py`
- `motor_feedback_listener.py`
- `robot_observation_bridge.py`

Main outputs:
- `/motor_can_feedback`
- `/motor_feedback`
- `/imu0`
- `/robot_observation`

Main inputs:
- `/robot_command`

Notable defaults:
- Full robot IDs enabled in command path:
  - `active_motor_ids="[1,2,3,4,5,6,7,8,9,10,11,12]"`
- Bus split defaults:
  - `left_bus_motor_ids="[1,3,5,7,9,11]"`
  - `right_bus_motor_ids="[2,4,6,8,10,12]"`
- `auto_enable=False`
- strict startup gate remains opt-in (`wait_for_expected_online_ids=False`)

When to use:
- You are running THOR policy runner manually in another terminal and want RL-ready topic wiring.

Example:
```bash
ros2 launch motor_control rl_robot_launch.py
```

## 3) thor_12_motor_pipeline_launch.py

Purpose:
- End-to-end orchestrator for 12-motor THOR policy execution.

Starts:
- Includes `rcu_launch.py` with full 12-motor arguments.
- Launches `hardware/thor/startup_then_policy_runner.py` via `ExecuteProcess`.

Main behavior:
- Brings up the RCU stack, ramps the robot from zero pose to standing, holds
  standing pose, then runs the standing policy — all in one process.
- Keyboard controls during runtime:
  - `p` — advance from STANDING_HOLD to POLICY
  - `h` — return to STANDING_HOLD from POLICY
  - `x` / Ctrl+C — safe exit (sends final standing pose)

Notable defaults:
- `auto_enable=True`
- `scan_motor_can_ids=True`
- startup gate enabled (`wait_for_expected_online_ids=True`)
- expected IDs set to all 12 motors

When to use:
- You want one launch command for full startup-to-policy execution.

Example:
```bash
ros2 launch motor_control thor_12_motor_pipeline_launch.py
```

## 4) rcu_bench_test_launch.py

Purpose:
- Bench workflow for commanding a small motor subset without full policy inference.

Starts:
- Includes `rcu_launch.py` configured for two-motor bench IDs.
- Launches `rcu_bench_command_test.py` command publisher.

Notable defaults:
- `active_motor_ids="[9,10]"`
- `left_bus_motor_ids="[9]"`
- startup gate enabled with expected IDs `[9,10]`
- command generator publishes on `/robot_command`

When to use:
- You are validating command path and motor response on bench hardware.

Example:
```bash
ros2 launch motor_control rcu_bench_test_launch.py
```

## 5) rcu_diagnosis_launch.py

Purpose:
- Bring-up/diagnosis mode focused on online CAN ID visibility and feedback monitoring.

Starts:
- `rcu_udp_bridge.py` (diagnosis parameters)
- `motor_feedback_listener.py`

Does not start:
- `robot_observation_bridge.py`

Notable defaults:
- `auto_enable=True`
- CAN-ID scan enabled
- startup gate enabled with expected IDs `[9,10]`
- targets diagnosis pair IDs 9 and 10 with bus overrides

When to use:
- You need to verify RCU link, detected motor IDs, and basic feedback stream before full control runs.

Example:
```bash
ros2 launch motor_control rcu_diagnosis_launch.py
```

## Relationship summary

- `rcu_launch.py` is the base reusable stack.
- `rcu_bench_test_launch.py` and `thor_12_motor_pipeline_launch.py` build on that base for specific workflows.
- `rl_robot_launch.py` is a direct RL-focused stack launch with broader parameter exposure and full 12-motor defaults.
- `rcu_diagnosis_launch.py` is intentionally diagnostic-first rather than full pipeline.

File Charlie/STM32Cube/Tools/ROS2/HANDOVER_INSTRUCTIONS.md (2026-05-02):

# PROJ500 Humanoid — RCU Motor Control Handover Instructions

**Document version:** 1.0  
**Date:** 2026-04-27  
**Author:** MCU team (Charlie)  
**Intended audience:** Thor ROS2 team  
**Purpose:** Complete, self-contained handover for integrating the RCU motor
control interface into the Thor ROS2 stack. Feed this document into an AI
assistant to generate missing code, or follow it step-by-step.

---

## 1. System Overview

The **RCU** (Robot Control Unit) is an STM32H723-based microcontroller that:
- Drives **12 RS04 motors** over two 1 Mbps CAN buses (FDCAN1=right, FDCAN3=left)
- Receives **UDP binary packets** from Thor on port 7701 (motor commands + supervisory)
- Transmits **UDP binary packets** to Thor on port 7700 (motor feedback, fast IMU, slow telem)
- Monitors the **PDU** (Power Distribution Unit) over a separate CAN bus (FDCAN2)

The **old** `ethernet_can_bridge.py` + `nucleo_can_bridge` serial bridge is **replaced** by
`rcu_udp_bridge.py` which speaks the RCU binary protocol directly.

---

## 2. Network Setup

| Device | Interface | Static IP | Notes |
|---|---|---|---|
| RCU (STM32H723) | Ethernet (RMII) | `192.168.100.10` | configured in CubeMX lwIP |
| Thor (Jetson/PC) | eth0 or enp... | `192.168.100.20` | must be on same subnet |

**Thor static IP setup (Ubuntu/ROS2):**
```bash
sudo ip addr add 192.168.100.20/24 dev eth0
sudo ip link set eth0 up
# Or persist via /etc/netplan or nmcli
```

**Ports:**
| Port | Direction | Content |
|---|---|---|
| 7700 | RCU → Thor | Slow telem (0x01), Motor FB (0x02), Fast IMU (0x04) |
| 7701 | Thor → RCU | Motor cmd (0x10), Motor supervisory (0x11), Debug cmd (0x20) |
| 7702 | RCU → Thor | Supervision events (0x03) |

**Firewall (if UFW is active):**
```bash
sudo ufw allow 7700/udp
sudo ufw allow 7701/udp
sudo ufw allow 7702/udp
```

---

## 3. Full Binary Protocol Reference

### 3.1 Packet Header (6 bytes, all packets)

```
Offset  Size  Field   Value
0       2     magic   0x5243 ('RC', little-endian)
2       1     type    packet type (see below)
3       1     seq     rolling counter 0–255
4       2     len     payload length in bytes (little-endian uint16)
```
Total frame size = 6 + len bytes. All multi-byte fields are **little-endian**.

### 3.2 Type 0x01 — Slow Telemetry (RCU → Thor, 10 Hz)

Payload: **72 bytes**. Format string: `"<6BH8h4h6h7h7h"`

| Offset | Type | Field | Units / Notes |
|---|---|---|---|
| 0 | u8 | fpga_status0 | FPGA status register 0 |
| 1 | u8 | fpga_fault_code | FPGA fault code |
| 2 | u8 | fpga_state_code | FPGA state machine code |
| 3 | u8 | fpga_actions | FPGA output actions |
| 4 | u8 | fpga_inputs | FPGA register 0x04 (e-stop/arm flags) |
| 5 | u8 | fpga_version | FPGA version register 0x7F |
| 6 | u16 | fpga_pchg_ms | Precharge timer [ms] |
| 8 | i16 | v_vraw_dv | VRAW voltage [10mV] → ÷100 for V |
| 10 | i16 | v_12v_mv | 12V rail [mV] → ÷1000 for V |
| 12 | i16 | v_24v_mv | 24V rail [mV] → ÷1000 for V |
| 14 | i16 | i_vraw_sw_ma | Switched VRAW current [mA] |
| 16 | i16 | i_12v_ma | 12V rail current [mA] |
| 18 | i16 | i_24v_ma | 24V rail current [mA] |
| 20 | i16 | therm1_dc | External thermistor 1 [0.1°C] |
| 22 | i16 | therm2_dc | External thermistor 2 [0.1°C] |
| 24 | i16 | ssd_i_ma | SSD energy meter current [mA] |
| 26 | i16 | ssd_v_dv | SSD voltage [10mV] |
| 28 | i16 | ssd_p_dw | SSD power [0.1W] |
| 30 | i16 | ssd_t_dc | SSD temperature [0.1°C] |
| 32 | i16 | ladc_therm0_dc | Board thermistor 0 [0.1°C] |
| 34 | i16 | ladc_therm1_dc | Board thermistor 1 [0.1°C] |
| 36 | i16 | ladc_therm2_dc | Board thermistor 2 [0.1°C] |
| 38 | i16 | ladc_vsource_mv | V_SOURCE [mV] |
| 40 | i16 | ladc_vbus_mv | V_BUS [mV] |
| 42 | i16 | ladc_icoil_ma | I_COIL [mA] |
| 44 | i16×3 | imu0_accel[xyz] | IMU0 accel raw — ×0.000122 → g |
| 50 | i16×3 | imu0_gyro[xyz] | IMU0 gyro raw — ×0.0175 → °/s |
| 56 | i16 | imu0_temp | IMU0 temp — ÷256 + 25 → °C |
| 58 | i16×3 | imu1_accel[xyz] | IMU1 accel raw |
| 64 | i16×3 | imu1_gyro[xyz] | IMU1 gyro raw |
| 70 | i16 | imu1_temp | IMU1 temp |

**Note:** The slow telem is for monitoring/logging only. Use Type 0x04 for the
RL control loop IMU (see §3.4).

### 3.3 Type 0x02 — Motor Feedback (RCU → Thor, 200 Hz)

Payload: **4 + n×10 bytes** (n ≤ 16 slots).

Header (4 bytes): `count(u8), pad[3]`

Per slot (10 bytes): `bus(u8), motor_id(u8), pos_u16, vel_u16, cur_u16, error(u8), mode_status(u8)`

`mode_status` is bits [23:22] of the RS04 Type-2 CAN ID: **0=idle/reset, 1=calibrating, 2=MIT running**.
A motor that has been enabled and is accepting MIT commands will show `mode_status=2`.

Decoding pos/vel/torque from uint16:
```python
pos_rad   = -12.57 + (pos_u16 / 65535.0) * (12.57 - (-12.57))
vel_rads  = -15.0  + (vel_u16 / 65535.0) * 30.0
torque_nm = -120.0 + (cur_u16 / 65535.0) * 240.0
```

The `/motor_can_feedback` ROS2 topic uses **8 bytes/motor** (float32 pos + float32 vel, LE),
ordered motor_id 1→12, totalling 96 bytes. This is consumed by `robot_observation_bridge.py`.

### 3.4 Type 0x04 — Fast IMU Packet (RCU → Thor, 200 Hz)

Payload: **28 bytes**. Format: `"<6h6hI"` (6×int16 + 6×int16 + uint32)

| Offset | Type | Field | Scale |
|---|---|---|---|
| 0 | i16×3 | imu0_accel[xyz] | ×0.000122 → g; ×(0.000122×9.81) → m/s² |
| 6 | i16×3 | imu0_gyro[xyz] | ×0.0175 → °/s; ×(0.0175×π/180) → rad/s |
| 12 | i16×3 | imu1_accel[xyz] | same as imu0 |
| 18 | i16×3 | imu1_gyro[xyz] | same as imu0 |
| 24 | u32 | tick_ms | HAL_GetTick() at RCU at time of packing |

Published to `/imu0` and `/imu1` as `sensor_msgs/Imu`.  
**This is the primary IMU source for the RL observation — not the slow telem.**

### 3.5 Type 0x10 — Motor Command (Thor → RCU)

Payload: **variable** (n × 10 bytes, one entry per motor).

Per entry (10 bytes):
```
bus(u8), motor_id(u8), pos_u16, vel_u16, trq_u16, kp_u8, kd_u8
```

In **CSP mode (Phase 1)**, only `pos_u16` is used. Encode with:
```python
pos_u16 = int((pos_rad - (-12.57)) / (25.14) * 65535)
```

In **MIT mode (Phase 2)**, all fields are used — see §9.

The `bus` field should be set from `MOTOR_BUS_MAP[motor_id]` (0=RIGHT, 1=LEFT).

### 3.6 Type 0x11 — Motor Supervisory (Thor → RCU)

Payload: **8 bytes**.

```
enable_mask    u16  bit N = enable motor_id N+1
clear_fault_mask u16  bit N = clear fault for motor_id N+1
ctrl_mode      u8   0=MIT Type1, 1=CSP param-write
_pad           u8×3
```

**Examples:**
```python
# Enable all 12 motors in CSP mode (Phase 1)
payload = struct.pack("<HHBxxx", 0x0FFF, 0x0FFF, 1)

# FULL E-STOP (disable all motors)
payload = struct.pack("<HHBxxx", 0x0000, 0x0000, 1)
```

### 3.7 Type 0x20 — Debug Command (Thor/PC → RCU)

Payload: `subcmd(u8) [+ extra bytes]`

| Sub-cmd | Value | Extra | Action |
|---|---|---|---|
| PING | 0x01 | — | Request immediate debug reply |
| BUZZ | 0x02 | — | 200ms buzzer pulse + PDU buzzer |
| LED_BLINK | 0x03 | — | Blink orange LED 3× |
| CAN_LOOPBACK | 0x04 | — | Run FDCAN1+FDCAN3 loopback, result in reply |
| FORCE_TELEM | 0x05 | — | Force immediate slow-telem TX |
| ASSERT_PDU_FAULT | 0x07 | `1=assert, 0=clear` | Assert/clear PDU power fault |
| SOFT_RESET | 0x08 | `0=RCU only` | NVIC_SystemReset() |
| SET_TELEM_RATE | 0x09 | Hz (5/10/20) | Change slow telem rate |
| MOTOR_BUS_CTRL | 0x0A | bitmask: bit0=L_STB, bit1=R_STB | CAN transceiver standby control |
| REQUEST_SUPV_DUMP | 0x0B | — | Force supervisory state dump to UART |
| MOTOR_ENABLE | 0x0C | `bus(u8), motor_id(u8), enable(u8), clr_fault(u8)` | Enable/disable one motor directly, bypasses MOTOR_BUS_MAP — use for bench testing |

**Full e-stop procedure uses TWO commands:**
1. Type 0x11 with `enable_mask=0` (stops motors via CAN Type 4)
2. Type 0x20 sub-cmd 0x07 with extra byte `0x01` (cuts PDU power rails)

Both must be sent. The RCU firmware handles them independently.

### 3.8 Type 0x21 — Debug Reply (RCU → Thor)

Payload: 20 bytes. Sent in response to any debug command.

---

## 4. Motor Joint Mapping

| motor_id | Joint Name | CAN Bus | Bus Num |
|---|---|---|---|
| 1 | pelvis_link_l_yaw_joint | FDCAN3 (left) | 1 |
| 2 | pelvis_link_r_yaw_joint | FDCAN1 (right) | 0 |
| 3 | l_hip_yaw_link_l_pitch_joint | FDCAN3 | 1 |
| 4 | r_hip_yaw_link_r_pitch_joint | FDCAN1 | 0 |
| 5 | l_hip_pitch_link_l_roll_joint | FDCAN3 | 1 |
| 6 | r_hip_pitch_link_r_roll_joint | FDCAN1 | 0 |
| 7 | l_thigh_link_l_knee_joint | FDCAN3 | 1 |
| 8 | r_thigh_link_r_knee_joint | FDCAN1 | 0 |
| 9 | l_shank_link_l_ankle_joint | FDCAN3 | 1 |
| 10 | r_shank_link_r_ankle_joint | FDCAN1 | 0 |
| 11 | l_ankle_link_l_foot_joint | FDCAN3 | 1 |
| 12 | r_ankle_link_r_foot_joint | FDCAN1 | 0 |

Bus mapping is hardcoded in `MOTOR_BUS_MAP[13]` in `rcu_protocol.py` and the
firmware's `motor_bus.h`. If motor IDs are reassigned, update BOTH.

---

## 5. E-Stop Procedure

### 5.1 Full E-Stop (recommended — use this in production)

```python
import rcu_protocol as rp
import socket

sock = socket.socket(socket.AF_INET, socket.SOCK_DGRAM)

# Step 1: Disable all motors via CAN (RS04 Type 4 to each motor)
sock.sendto(rp.encode_motor_supervisory(enable_mask=0x0000),
            (rp.RCU_IP, rp.PORT_CMD))

# Step 2: Assert PDU fault (cuts 12V/24V/VRAW power rails entirely)
sock.sendto(rp.encode_debug_cmd(rp.DBGCMD_ASSERT_PDU_FAULT, bytes([1])),
            (rp.RCU_IP, rp.PORT_CMD))
```

Both steps are sent immediately. Step 2 is the physical power cut.

### 5.2 Software-Only Motor Stop (for bench testing / mode switching)

```python
sock.sendto(rp.encode_motor_supervisory(enable_mask=0x0000),
            (rp.RCU_IP, rp.PORT_CMD))
# PDU power remains on — motors are free-wheeling
```

### 5.3 PDU Fault Recovery

```python
# Clear fault (restore power)
sock.sendto(rp.encode_debug_cmd(rp.DBGCMD_ASSERT_PDU_FAULT, bytes([0])),
            (rp.RCU_IP, rp.PORT_CMD))
# Then re-enable motors
sock.sendto(rp.encode_motor_supervisory(enable_mask=0x0FFF,
                                         clear_fault_mask=0x0FFF,
                                         ctrl_mode=1),
            (rp.RCU_IP, rp.PORT_CMD))
```

---

## 6. Motor Enable Sequence

The RCU firmware handles the enable sequence automatically when Type 0x11 is received
with `enable_mask != 0`. For reference, the CAN frames sent per motor are:

**CSP mode (`ctrl_mode=1`):**
1. **RS04 Type 18** param write: `run_mode = 5` (CSP position mode)
2. **RS04 Type 3** COMM_ENABLE
3. **RS04 Type 18** param write: `limit_spd = 15.0` rad/s

**MIT mode (`ctrl_mode=0`, default):**
1. **RS04 Type 18** param write: `run_mode = 0` (MIT / operation control mode)
2. **RS04 Type 3** COMM_ENABLE

The `run_mode` write must precede COMM_ENABLE in both cases — the motor ignores mode
changes while already enabled. The firmware enforces this order.

**Firmware default is MIT (`ctrl_mode=0`).** If you want CSP, you must send Type 0x11
with `ctrl_mode=1` explicitly.

---

## 7. File Placement in ROS2 Package

Assuming your ROS2 package is named `proj500_control` inside `src/`:

```
src/
  proj500_control/
    proj500_control/
      rcu_udp_bridge.py       ← copy from Tools/ROS2/
      rcu_protocol.py         ← copy from Tools/
      robot_command_bridge.py  ← your existing file
      robot_observation_bridge.py ← your existing file
    launch/
      rcu_launch.py           ← copy from Tools/ROS2/
    setup.py
    package.xml
    CMakeLists.txt
```

### 7.1 setup.py Changes

Add to `entry_points['console_scripts']`:
```python
"rcu_udp_bridge = proj500_control.rcu_udp_bridge:main",
```

### 7.2 package.xml Changes

Add inside `<package>`:
```xml
<exec_depend>rclpy</exec_depend>
<exec_depend>std_msgs</exec_depend>
<exec_depend>sensor_msgs</exec_depend>
<exec_depend>std_srvs</exec_depend>
```

### 7.3 CMakeLists.txt (if using ament_cmake_python)

```cmake
ament_python_install_package(${PROJECT_NAME})

install(PROGRAMS
  proj500_control/rcu_udp_bridge.py
  proj500_control/rcu_protocol.py
  DESTINATION lib/${PROJECT_NAME}
)

install(DIRECTORY launch/
  DESTINATION share/${PROJECT_NAME}/launch
)
```

### 7.4 Update launch file

In `rcu_launch.py`, replace `<your_ros2_package>` with `proj500_control` (or your actual
package name). Update `executable` names to match your `setup.py` entry points.

---

## 8. Testing Sequence

### Step 1: Network connectivity
```bash
ping 192.168.100.10          # RCU must respond
```

### Step 2: Slow telem check
```bash
python Tools/rcu_monitor.py  # existing tool — should show PDU data at 10 Hz
```

### Step 3: Bench tool (no motors)
```bash
python Tools/rcu_motor_test.py
# Press 'p' → should see debug reply with uptime_ms > 0
# Note: motor_fb table will show '--' until motors are connected
```

### Step 4: Single motor test (one RS04 connected)
```
In rcu_motor_test.py:
1. Press '1' to select motor 1
2. Press 'e' to enable (observe: motor LED changes, motor holds position)
3. Press ']' three times (motor should move ~0.6 rad total)
4. Press 'h' (motor should return to 0 rad)
5. Press 'd' for full e-stop (motor de-energises, PDU power cuts)
6. Verify PDU fault cleared before re-enabling: press 'd' then PDU fault clears, then 'e'
```

### Step 5: Fast IMU verification
```bash
python -c "
import socket, rcu_protocol as rp, time
s = socket.socket(socket.AF_INET, socket.SOCK_DGRAM)
s.bind(('', rp.PORT_TELEM))
s.settimeout(1.0)
count = 0
t0 = time.time()
while time.time() - t0 < 2.0:
    try:
        d, _ = s.recvfrom(256)
        h = rp.parse_header(d)
        if h and h[0] == rp.PKT_IMU_FAST:
            count += 1
    except: pass
print(f'IMU fast packets in 2s: {count} (expected ~400)')
"
```

### Step 6: ROS2 integration
```bash
# Terminal 1
ros2 launch proj500_control rcu_launch.py

# Terminal 2 — verify fast IMU at ~200 Hz
ros2 topic hz /imu0

# Terminal 3 — verify motor feedback
ros2 topic echo /motor_can_feedback --no-arr

# Terminal 4 — test enable via service
ros2 service call /rcu_motor_estop std_srvs/srv/SetBool "{data: true}"

# Terminal 4 — test e-stop
ros2 service call /rcu_motor_estop std_srvs/srv/SetBool "{data: false}"
```

---

## 9. Phase 2 — MIT Impedance Control Migration

Phase 1 uses CSP position control (parameter write, proven simple and robust).
Phase 2 uses MIT impedance control (Type 1 CAN frame with full pos/vel/kp/kd/torque)
for the RL policy output. **No firmware changes are needed** — only the supervisory
packet `ctrl_mode` field changes.

> **Note:** The firmware now defaults to MIT (`g_ctrl_mode=0`). Phase 1 CSP requires
> explicitly sending `ctrl_mode=1` in every Type 0x11 packet.

### Activating Phase 2

```python
# Send Type 0x11 with ctrl_mode=0 (MIT) — this is already the firmware default
sock.sendto(rp.encode_motor_supervisory(
    enable_mask=0x0FFF,
    clear_fault_mask=0x0FFF,
    ctrl_mode=0     # MIT impedance control
), (rp.RCU_IP, rp.PORT_CMD))
```

The firmware writes `run_mode=0` before COMM_ENABLE, then accepts Type 1 CAN frames.

### Type 0x10 command entries in MIT mode

All fields are now used:
```python
entry = rcu_protocol.encode_motor_cmd_entry(
    motor_id=1,
    bus=1,           # from MOTOR_BUS_MAP
    pos_rad=theta,   # RL target position
    vel_rads=dtheta, # RL target velocity
    torque_nm=tau,   # feedforward torque
    kp=200.0,        # position gain (0–5000)
    kd=5.0,          # velocity damping (0–100)
)
```

The MIT control law on the motor is:
`torque = Kd*(vel_target - vel_actual) + Kp*(pos_target - pos_actual) + torque_ff`

### rcu_launch.py change
```python
# Change ctrl_mode parameter from "1" to "0"
"ctrl_mode": "0",
```

---

## 10. Known Caveats and Notes

1. **motor_id=0 is invalid** — always rejected by firmware. Motor IDs start at 1.

2. **Mode change requires disabled state** — the RCU firmware handles this: it always
   writes `run_mode` BEFORE sending the Type 3 enable frame. Do not send mode changes
   to an already-enabled motor. Use the supervisory packet to disable first.

3. **CAN bus loading at 200 Hz** — 12 motors × `loc_ref` param writes ≈ 2400 CAN
   frames/sec across two 1 Mbps buses (≈10% utilisation per bus). Monitor FDCAN
   TX FIFO overflow counters via the debug reply `can_loopback` field if latency
   is observed.

4. **IMU ODR must be ≥200 Hz** — verify the ICM IMU on the RCU is configured for
   at least 200 Hz output data rate. The RCU firmware polls `imu_get_sample()` at
   200 Hz from the fast loop. If the ODR is lower, the fast IMU packets will contain
   duplicate samples.

5. **Ethernet link must be 1000BASE-T or 100BASE-TX** — the RCU uses RMII. A
   10BASE-T switch between RCU and Thor will add ~1 ms latency per packet.
   Use a direct cable or a GbE switch.

6. **PDU fault recovery** — after asserting PDU fault (full e-stop), the 12V/24V/VRAW
   rails are cut. Motors lose power. To recover: (a) send clear-fault debug cmd 0x07
   with byte=0, (b) wait ~500 ms for rails to ramp up, (c) re-enable motors via
   Type 0x11.

7. **RS04 CAN_TIMEOUT** — the RS04 motor has a configurable CAN watchdog
   (`CAN_TIMEOUT` parameter, function code `0x200B`). Default is 0 (disabled). If
   you enable it (e.g. 200000 = 10 s), the motor will reset itself if no CAN frame
   is received for that duration. Keep this in mind during debug pauses.

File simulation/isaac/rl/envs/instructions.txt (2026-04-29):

This is moving the fridge to the directory I want it in

cd C:\Users\TheFridge\Documents\GitHub\MEng-PROJ500-2025-26

This Runs the RL policy heedlessly

cmd /c "C:\Users\TheFridge\Documents\GitHub\IsaacLab\isaaclab.bat -p simulation/isaac/rl/train_walk_s2r.py --headless"

FOR PLAYBACK
separate terminal 

Move Directory 
cd C:\Users\TheFridge\Documents\GitHub\MEng-PROJ500-2025-26

Play the walking back (change the log number the date looking one to whatever the most
recent output is)

 & "C:\Users\TheFridge\Documents\GitHub\IsaacLab\isaaclab.bat" -p simulation/isaac/rl/play_walk_s2r.py --num_envs 1 --checkpoint "C:\Users\TheFridge\Documents\GitHub\MEng-PROJ500-2025-26\logs\rsl_rl\humanoid_walk\2026-04-28_11-46-49\model_199.pt"
	
le

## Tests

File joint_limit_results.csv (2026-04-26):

joint_index | joint_name | lower_limit_rad | upper_limit_rad | neutral_ref_rad | target_lower_rad | reached_lower_rad | lower_error_rad | target_upper_rad | reached_upper_rad | upper_error_rad | pass_neutral_1 | pass_lower | pass_neutral_2 | pass_upper | pass_neutral_3 | overall_pass
0 | pelvis_link_l_yaw_joint | -0.5235990285873413 | 0.5235990285873413 | 0.0 | -0.4712391257286072 | -0.4712185263633728 | 2.0599365234408307e-05 | 0.4712391257286072 | 0.4712187349796295 | -2.039074897769444e-05 | True | True | True | True | True | True
1 | pelvis_link_r_yaw_joint | -0.5235990285873413 | 0.5235990285873413 | 0.0 | -0.4712391257286072 | -0.4712187647819519 | 2.0360946655306744e-05 | 0.4712391257286072 | 0.4712189733982086 | -2.0152330398592877e-05 | True | True | True | True | True | True
2 | l_hip_yaw_link_l_pitch_joint | -0.6981319785118103 | 1.0471980571746826 | 0.0 | -0.6283187806606293 | -0.6283207535743713 | -1.9729137420432252e-06 | 0.9424782514572144 | 0.9424944519996643 | 1.620054244988456e-05 | True | True | True | True | True | True
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

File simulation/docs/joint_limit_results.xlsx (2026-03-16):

joint_index | joint_name | lower_limit_rad | upper_limit_rad | neutral_ref_rad | target_lower_rad | reached_lower_rad | lower_error_rad | target_upper_rad | reached_upper_rad | upper_error_rad | pass_neutral_1 | pass_lower | pass_neutral_2 | pass_upper | pass_neutral_3 | overall_pass
0 | robot_pelvis_link_l_yaw_joint | -0.5235990286 | 0.5235990286 | 0 | -0.4712391257 | -0.4712196589 | 1.946687698e-05 | 0.4712391257 | 0.4712197781 | -1.934766769e-05 | TRUE | TRUE | TRUE | TRUE | TRUE | TRUE
1 | robot_pelvis_link_r_yaw_joint | -0.5235990286 | 0.5235990286 | 0 | -0.4712391257 | -0.4712198973 | 1.92284584e-05 | 0.4712391257 | 0.4712200165 | -1.910924912e-05 | TRUE | TRUE | TRUE | TRUE | TRUE | TRUE
2 | robot_l_hip_yaw_link_l_pitch_joint | -1.047198057 | 0.6981319785 | 0 | -0.9424782515 | -0.9426605105 | -0.0001822590828 | 0.6283187807 | 0.6284232736 | 0.0001044929028 | TRUE | TRUE | TRUE | TRUE | TRUE | TRUE
3 | robot_r_hip_yaw_link_r_pitch_joint | -1.047198057 | 0.6981319785 | 0 | -0.9424782515 | -0.9427039623 | -0.0002257108688 | 0.6283187807 | 0.628451407 | 0.0001326262951 | TRUE | TRUE | TRUE | TRUE | TRUE | TRUE
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

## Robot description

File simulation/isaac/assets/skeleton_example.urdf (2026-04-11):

<?xml version='1.0' encoding='utf-8'?>
<robot name="Robot">
    <link name="isaac_zup_root" />
    <link name="robot_torso_link">
        <inertial>
            <origin xyz="0.040610506256969305 -0.04428824001105586 0.15232735840638484" rpy="0 0 0" />
            <mass value="3.4766230099551185" />
            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
        </inertial>
        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
    </link>
    <link name="robot_pelvis_link">
        <inertial>
            <origin xyz="1.907307843025983e-09 0.8221283725272435 -0.16050000000009512" rpy="0 0 0" />
            <mass value="0.4703666239440356" />
            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
        </inertial>
        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
    </link>
    <link name="robot_l_hip_yaw_link">
        <inertial>
            <origin xyz="0.06170580963744355 1.9456187771993428e-11 0.06827606857409776" rpy="0 0 0" />
            <mass value="6.333603185323419" />
            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
        </inertial>
        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
    </link>
    <link name="robot_l_hip_pitch_link">
        <inertial>
            <origin xyz="-0.02696184868350109 5.718654837338022e-05 0.07266905837477193" rpy="0 0 0" />
            <mass value="2.4943200880759124" />
            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
        </inertial>
        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
    </link>
    <link name="robot_l_thigh_link">
        <inertial>
            <origin xyz="-0.013245029323109475 -0.004137655727869163 -0.2579314528909593" rpy="0 0 0" />
            <mass value="3.0917752218546957" />
            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
        </inertial>
        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
    </link>
    <link name="robot_l_shank_link">
        <inertial>
            <origin xyz="-3.0467861478200577e-09 0.14999999550286972 0.02088709684404469" rpy="0 0 0" />
            <mass value="0.8515894596853654" />
            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
        </inertial>
        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
    </link>
    <link name="robot_l_ankle_link">
        <inertial>
            <origin xyz="0.0025101642045814642 -2.9435578429026778e-06 0.027693209476934388" rpy="0 0 0" />
            <mass value="2.497542686119488" />
            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
        </inertial>
        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
    </link>
    <link name="robot_l_foot_link">
        <inertial>
            <origin xyz="2.1152900764320747e-09 0.021295071129086525 0.009743852524883821" rpy="0 0 0" />
            <mass value="2.78967156731517" />
            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
        </inertial>
        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
    </link>
    <link name="robot_r_hip_yaw_link">
        <inertial>
            <origin xyz="-0.06170580582138252 -1.9462511602341692e-11 -0.06827606857536807" rpy="0 0 0" />
            <mass value="6.33360318547509" />
            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
        </inertial>
        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
    </link>
    <link name="robot_r_hip_pitch_link">
        <inertial>
            <origin xyz="-0.026950752726990004 -4.887744043458043e-07 0.07268407470290571" rpy="0 0 0" />
            <mass value="2.4943200880759147" />
            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
        </inertial>
        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
    </link>
    <link name="robot_r_thigh_link">
        <inertial>
            <origin xyz="0.013245027463409737 0.004137658774629856 0.2579314573880829" rpy="0 0 0" />
            <mass value="3.0917752218546957" />
            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
        </inertial>
        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
    </link>
    <link name="robot_r_shank_link">
        <inertial>
            <origin xyz="0 -0.14999999999999544 0.02088709874680781" rpy="0 0 0" />
            <mass value="0.8515894596853654" />
            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
        </inertial>
        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
    </link>
    <link name="robot_r_ankle_link">
        <inertial>
            <origin xyz="0.0025096858438951133 4.881742454987403e-07 0.02773418951986404" rpy="0 0 0" />
            <mass value="2.4975426861194876" />
            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
        </inertial>
        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
    </link>
    <link name="robot_r_foot_link">
        <inertial>
            <origin xyz="1.6993186235936263e-09 -0.02129507460669811 -0.009743852524875" rpy="0 0 0" />
            <mass value="2.7896715673151693" />
            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
        </inertial>
        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
    </link>
    <joint name="isaac_zup_root_joint" type="fixed">
        <parent link="isaac_zup_root" />
        <child link="robot_pelvis_link" />
        <origin xyz="0 0 0" rpy="1.57079632679 0 1.57079632679" />
    </joint>
    <joint name="robot_pelvis_link_l_yaw_joint" type="revolute">
        <origin xyz="0.12000000000000094 0.8127999999999959 -0.1604999999999903" rpy="1.5707963267949308 0 0" />
        <parent link="robot_pelvis_link" />
        <child link="robot_l_hip_yaw_link" />
        <axis xyz="0 0 1.0" />
        <limit lower="-0.523599" upper="0.523599" effort="60" velocity="6" />
    </joint>
    <joint name="robot_l_hip_yaw_link_l_pitch_joint" type="revolute">
        <origin xyz="0.07499999999999987 0 0.13629999999999995" rpy="-1.5707963267948966 0 1.5707963267948966" />
        <parent link="robot_l_hip_yaw_link" />
        <child link="robot_l_hip_pitch_link" />
        <axis xyz="0 0 -1.0" />
        <limit lower="-1.047198" upper="0.698132" effort="60" velocity="6" />
    </joint>
    <joint name="robot_l_hip_pitch_link_l_roll_joint" type="revolute">
        <origin xyz="0.0004884400000000255 5.907999999990921e-05 0.07498434999999998" rpy="-1.5707963267949294 1.5707963267948966 0" />
        <parent link="robot_l_hip_pitch_link" />
        <child link="robot_l_thigh_link" />
        <axis xyz="0 1.0 0" />
        <limit lower="-0.436332" upper="0.436332" effort="60" velocity="6" />
    </joint>
    <joint name="robot_l_thigh_link_l_knee_joint" type="revolute">
        <origin xyz="0.0129999999999999 0.0005000000000097771 -0.3" rpy="-1.5707963267948981 0 -1.5707963267948966" />
        <parent link="robot_l_thigh_link" />
        <child link="robot_l_shank_link" />
        <axis xyz="0 0 -1.0" />
        <limit lower="-2.094395" upper="0.0" effort="90" velocity="8" />
    </joint>
    <joint name="robot_l_shank_link_l_ankle_joint" type="revolute">
        <origin xyz="0 0.3 0" rpy="-3.141592653589792 0 0" />
        <parent link="robot_l_shank_link" />
        <child link="robot_l_ankle_link" />
        <axis xyz="0 0 1.0" />
        <limit lower="-0.610865" upper="0.436332" effort="45" velocity="10" />
    </joint>
    <joint name="robot_l_ankle_link_l_foot_joint" type="revolute">
        <origin xyz="0.07401155999999999 -5.9079999999998025e-05 0.009015649999999998" rpy="1.5707963267948966 1.5707963267948966 0" />
        <parent link="robot_l_ankle_link" />
        <child link="robot_l_foot_link" />
        <axis xyz="0 1.0 0" />
        <limit lower="-0.261799" upper="0.261799" effort="45" velocity="10" />
    </joint>
    <joint name="robot_pelvis_link_r_yaw_joint" type="revolute">
        <origin xyz="-0.11999999999999826 0.8127999999999959 -0.1604999999999903" rpy="-1.5707963267948628 0 0" />
        <parent link="robot_pelvis_link" />
        <child link="robot_r_hip_yaw_link" />
        <axis xyz="0 0 1.0" />
        <limit lower="-0.523599" upper="0.523599" effort="60" velocity="6" />
    </joint>
    <joint name="robot_r_hip_yaw_link_r_pitch_joint" type="revolute">
        <origin xyz="-0.07499999999999991 0 -0.13629999999999995" rpy="-1.5707963267948966 0 -1.5707963267948966" />
        <parent link="robot_r_hip_yaw_link" />
        <child link="robot_r_hip_pitch_link" />
        <axis xyz="0 0 1.0" />
        <limit lower="-1.047198" upper="0.698132" effort="60" velocity="6" />
    </joint>
    <joint name="robot_r_hip_pitch_link_r_roll_joint" type="revolute">
        <origin xyz="0.0005000000000000072 0 0.07500000000000002" rpy="-1.5707963267948637 -1.5707963267948966 0" />
        <parent link="robot_r_hip_pitch_link" />
        <child link="robot_r_thigh_link" />
        <axis xyz="0 1.0 0" />
        <limit lower="-0.436332" upper="0.436332" effort="60" velocity="6" />
    </joint>
    <joint name="robot_r_thigh_link_r_knee_joint" type="revolute">
        <origin xyz="-0.013000000000000185 -0.0004999999999901661 0.3000000000000001" rpy="-1.570796326794898 0 1.5707963267948966" />
        <parent link="robot_r_thigh_link" />
        <child link="robot_r_shank_link" />
        <axis xyz="0 0 1.0" />
        <limit lower="-2.094395" upper="0.0" effort="90" velocity="8" />
    </joint>
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

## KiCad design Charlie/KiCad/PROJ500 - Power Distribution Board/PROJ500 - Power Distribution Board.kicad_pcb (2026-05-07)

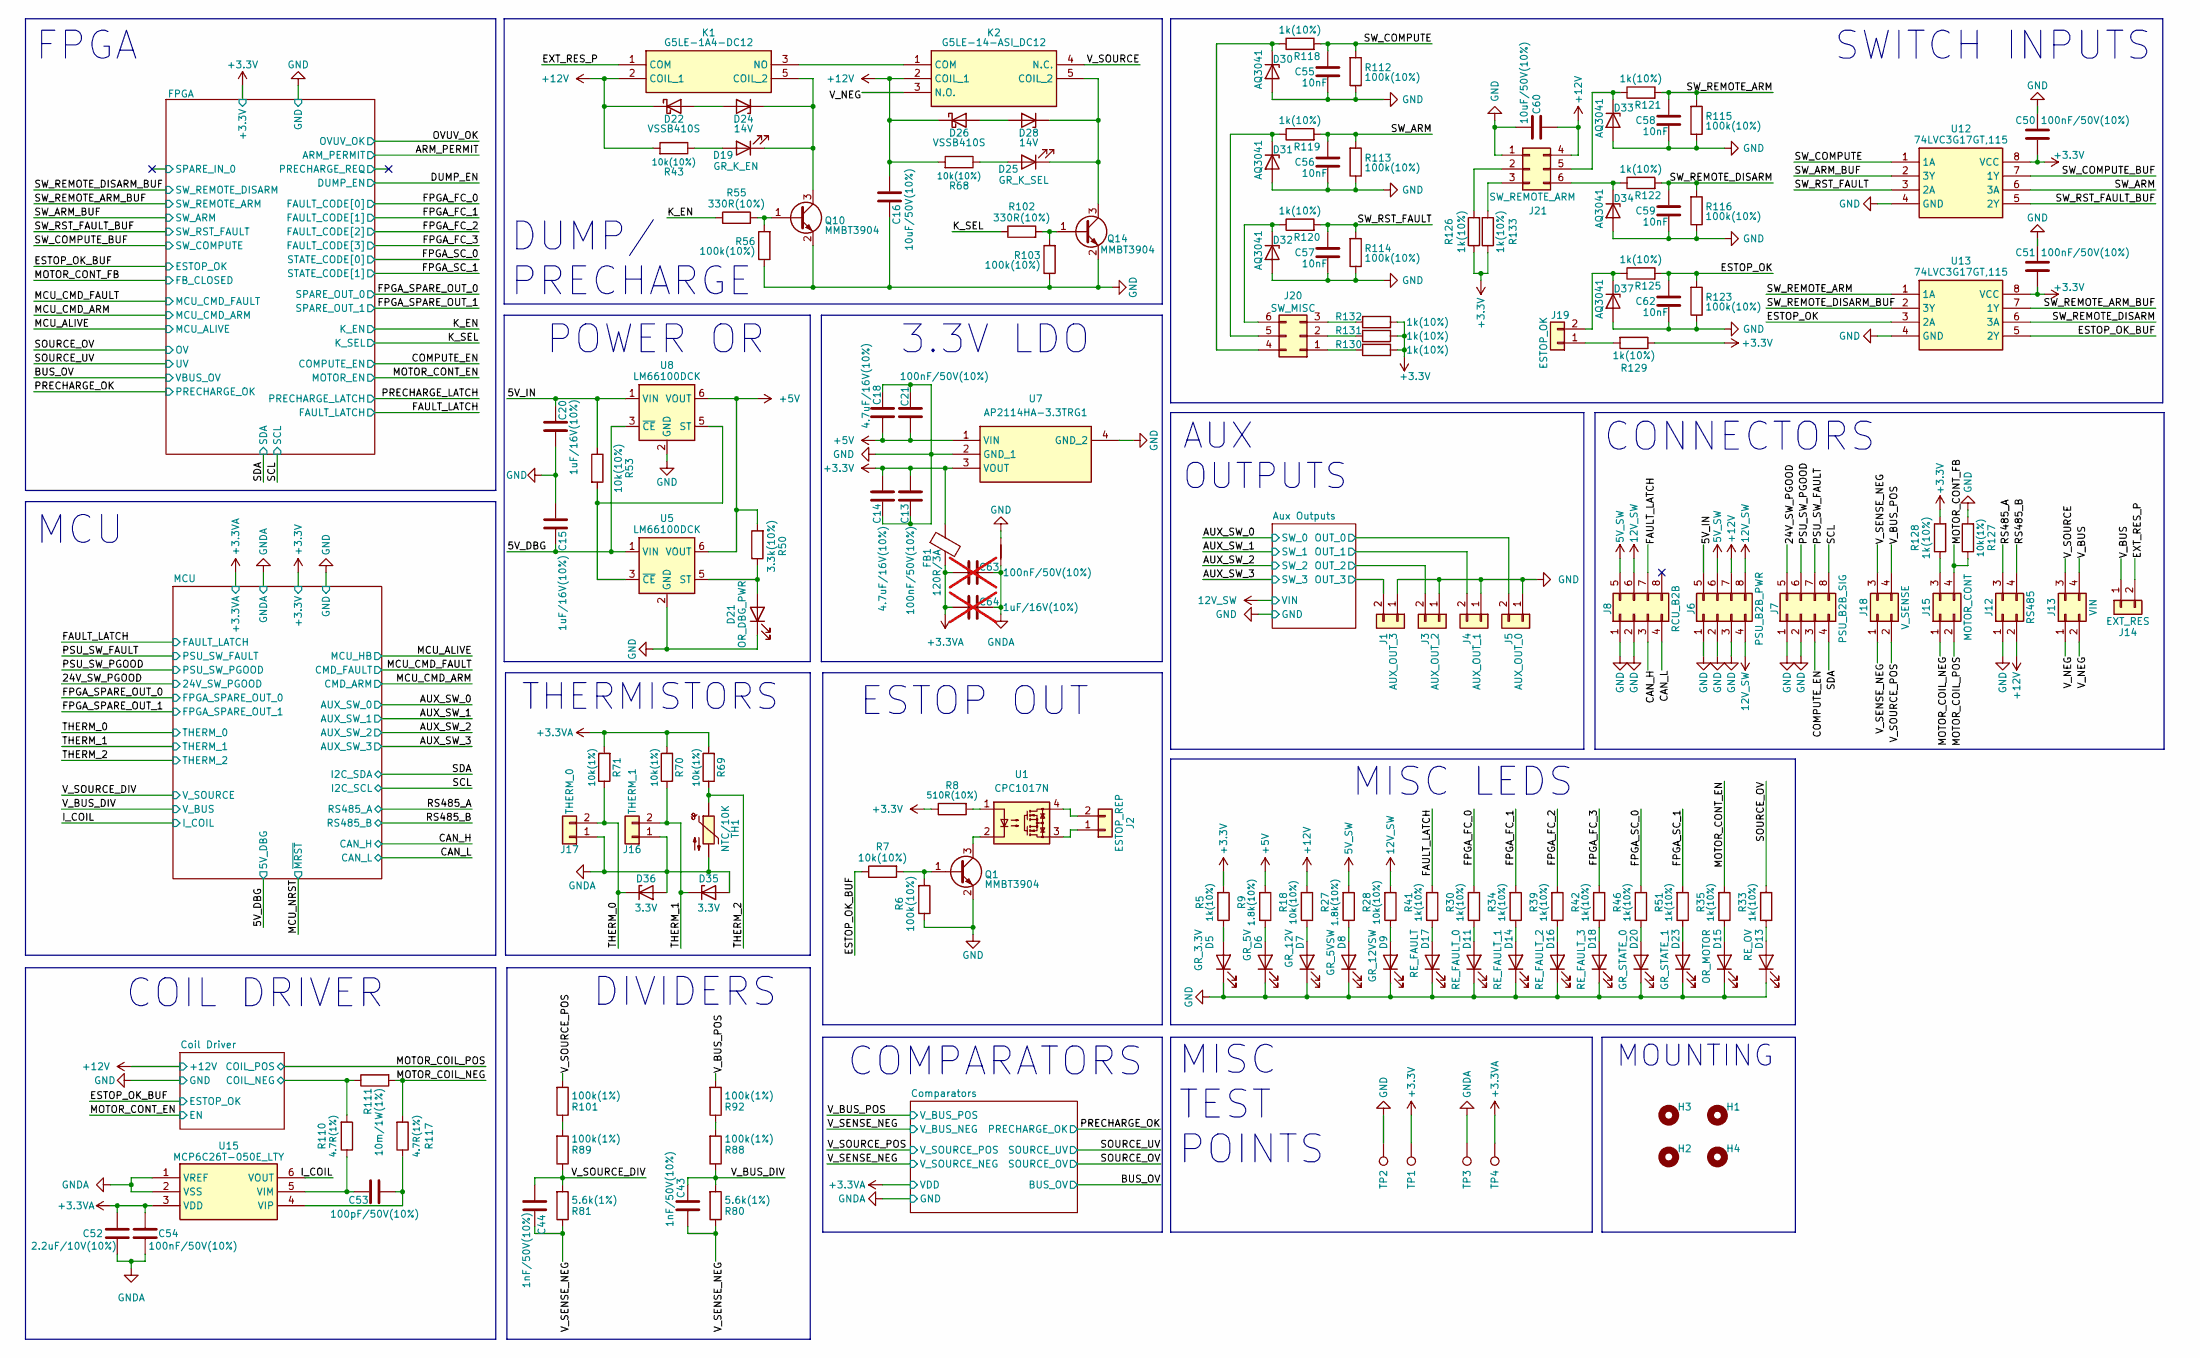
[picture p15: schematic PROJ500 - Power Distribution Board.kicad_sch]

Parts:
C13, C21, C50, C51, C54: 100nF/50V(10%); C_0402_1005Metric
C14, C18: 4.7uF/16V(10%); C_0805_2012Metric
C15, C20: 1uF/16V(10%); C_0603_1608Metric
C16, C60: 10uF/50V(10%); C_1206_3216Metric
C43, C44: 1nF/50V(10%); C_0402_1005Metric
C52: 2.2uF/10V(10%); C_0603_1608Metric
C53: 100pF/50V(10%); C_0402_1005Metric
C55, C56, C57, C58, C59, C62: 10nF/50V(10%); C_0402_1005Metric
C63: 100nF/50V(10%); C_0402_1005Metric; not fitted
C64: 1uF/16V(10%); C_0603_1608Metric; not fitted
D5: GR_3.3V; D_0805_2012Metric
D6: GR_5V; D_0805_2012Metric
D7: GR_12V; D_0805_2012Metric
D8: GR_5VSW; D_0805_2012Metric
D9: GR_12VSW; D_0805_2012Metric
D11: RE_FAULT_0; D_0805_2012Metric
D13: RE_OV; D_0805_2012Metric
D14: RE_FAULT_1; D_0805_2012Metric
D15: OR_MOTOR; D_0805_2012Metric
D16: RE_FAULT_2; D_0805_2012Metric
D17: RE_FAULT; D_0805_2012Metric
D18: RE_FAULT_3; D_0805_2012Metric
D19: GR_K_EN; D_0805_2012Metric
D20: GR_STATE_0; D_0805_2012Metric
D21: OR_DBG_PWR; D_0805_2012Metric
D22, D26: VSSB410S; D_SMB
D23: GR_STATE_1; D_0805_2012Metric
D24, D28: 14V; D_SOD-123
D25: GR_K_SEL; D_0805_2012Metric
D30, D31, D32, D33, D34, D37: AQ3041; D_SOD-882
D35, D36: 3.3V; D_SOD-123
FB1: 120R/3A; L_0603_1608Metric
H1, H2, H3, H4: MountingHole; MountingHole_3.2mm_M3
J1: AUX_OUT_3; TBP02R138102BE
J2: ESTOP_REP; TBP02R138102BE
J3: AUX_OUT_2; TBP02R138102BE
J4: AUX_OUT_1; TBP02R138102BE
J5: AUX_OUT_0; TBP02R138102BE
J6: PSU_B2B_PWR; Molex_Micro-Fit_3.0_43045-0800_2x04_P3.00mm_Horizontal
J7: PSU_B2B_SIG; Molex_Micro-Fit_3.0_43045-0800_2x04_P3.00mm_Horizontal
J8: RCU_B2B; Molex_Micro-Fit_3.0_43045-0800_2x04_P3.00mm_Horizontal
J12: RS485; Molex_Micro-Fit_3.0_43045-0400_2x02_P3.00mm_Horizontal
J13: VIN; Molex_Micro-Fit_3.0_43045-0400_2x02_P3.00mm_Horizontal
J14: EXT_RES; Molex_Micro-Fit_3.0_43045-0200_2x01_P3.00mm_Horizontal
J15: MOTOR_CONT; Molex_Micro-Fit_3.0_43045-0400_2x02_P3.00mm_Horizontal
J16: THERM_1; Molex_Micro-Fit_3.0_43045-0200_2x01_P3.00mm_Horizontal
J17: THERM_0; Molex_Micro-Fit_3.0_43045-0200_2x01_P3.00mm_Horizontal
J18: V_SENSE; Molex_Micro-Fit_3.0_43045-0400_2x02_P3.00mm_Horizontal
J19: ESTOP_OK; Molex_Micro-Fit_3.0_43045-0200_2x01_P3.00mm_Horizontal
J20: SW_MISC; Molex_Micro-Fit_3.0_43045-0600_2x03_P3.00mm_Horizontal
J21: SW_REMOTE_ARM; Molex_Micro-Fit_3.0_43045-0600_2x03_P3.00mm_Horizontal
K1: G5LE-1A4-DC12; G5LE1A4DC12; Mouser Part Number 653-G5LE-1A4-DC12
K2: G5LE-14-ASI_DC12; G5LE-14_SPDT; Mouser Part Number 653-G5LE-14-ASIDC12
NT1: NetTie_2; NetTie-2_SMD_Pad0.5mm
Q1, Q10, Q14: MMBT3904; SOT-23
R5, R30, R33, R34, R35, R39, R41, R42, R46, R51, R118, R119, R120, R121, R122, R125, R126, R128, R129, R130, R131, R132, R133: 1k(10%); R_0402_1005Metric
R6, R56, R103, R112, R113, R114, R115, R116, R123: 100k(10%); R_0402_1005Metric
R7, R18, R28, R43, R53, R68: 10k(10%); R_0402_1005Metric
R8: 510R(10%); R_0402_1005Metric
R9, R27: 1.8k(10%); R_0402_1005Metric
R50: 3.3k(10%); R_0402_1005Metric
R55, R102: 330R(10%); R_0402_1005Metric
R69, R70, R71, R127: 10k(1%); R_0402_1005Metric
R80, R81: 5.6k(1%); R_0402_1005Metric
R88, R89, R92, R101: 100k(1%); R_0603_1608Metric
R110, R117: 4.7R(1%); R_0402_1005Metric
R111: 10m/1W(1%); R_2512_6332Metric
TH1: NTC/10K; R_0402_1005Metric
TP1, TP2, TP3, TP4: TestPoint; TestPoint_Pad_D1.0mm
U1: CPC1017N; SOP-4_3.8x4.1mm_P2.54mm
U5, U8: LM66100DCK; SOT-363_SC-70-6
U7: AP2114HA-3.3TRG1; SOT-223; Mouser Part Number 621-AP2114HA-3.3TRG1
U12, U13: 74LVC3G17GT,115; XC7WT14GT115; Mouser Part Number 771-LVC3G17GT115
U15: MCP6C26T-050E_LTY; SOT-363_SC-70-6; Manufacturer_Part_Number MCP6C26T-050E/LTY

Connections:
5V_SW: J6.6, J8.5, R27.2
12V_SW: J6.4, J6.8, J8.6, R28.2; also elsewhere on the board
+3.3V: C13.1, C14.2, C50.1, C51.1, FB1.1, R5.2, R8.1, R126.1, R128.2, R129.1, R130.1, R131.1, R132.1, R133.1, TP1.1, U7.3 (VOUT), U12.8 (VCC), U13.8 (VCC); also elsewhere on the board
+3.3VA: C52.1, C54.1, C63.1, C64.2, FB1.2, R69.2, R70.2, R71.2, TP4.1, U15.3 (VDD); also elsewhere on the board
+5V: C18.2, C21.1, R9.2, R50.2, U5.6 (VOUT), U7.1 (VIN), U8.6 (VOUT)
+12V: C16.2, C60.2, D22.1 (K), D26.1 (K), J6.7, J12.2, J21.4, K1.2 (COIL_1), K2.2 (COIL_1), R18.2, R43.2, R68.2; also elsewhere on the board
/5V_DBG: C15.2, U5.1 (VIN), U8.3 (~CE); also elsewhere on the board
/5V_IN: C20.1, J6.5, R53.1, U8.1 (VIN)
/24V_SW_PGOOD: J7.5; also elsewhere on the board
/Aux Outputs/OUT_0: J5.2; also elsewhere on the board
/Aux Outputs/OUT_1: J4.2; also elsewhere on the board
/Aux Outputs/OUT_2: J3.2; also elsewhere on the board
/Aux Outputs/OUT_3: J1.2; also elsewhere on the board
/CAN_H: J8.3; also elsewhere on the board
/CAN_L: J8.4; also elsewhere on the board
/COMPUTE_EN: J7.3; also elsewhere on the board
/Coil Driver/COIL_NEG: R110.2, R111.1; also elsewhere on the board
/ESTOP_OK: C62.1, R123.2, R125.2, U13.3 (2A)
/ESTOP_OK_BUF: R7.1, U13.5 (2Y); also elsewhere on the board
/EXT_RES_P: J14.2, K1.1 (COM)
/FAULT_LATCH: J8.7, R41.2; also elsewhere on the board
/FPGA_FC_0: R30.2; also elsewhere on the board
/FPGA_FC_1: R34.2; also elsewhere on the board
/FPGA_FC_2: R39.2; also elsewhere on the board
/FPGA_FC_3: R42.2; also elsewhere on the board
/FPGA_SC_0: R46.2; also elsewhere on the board
/FPGA_SC_1: R51.2; also elsewhere on the board
/I_COIL: U15.6 (VOUT); also elsewhere on the board
/K_EN: R55.1; also elsewhere on the board
/K_SEL: R102.1; also elsewhere on the board
/MOTOR_COIL_NEG: J15.1, R111.2, R117.2
/MOTOR_COIL_POS: J15.2; also elsewhere on the board
/MOTOR_CONT_EN: R35.2; also elsewhere on the board
/MOTOR_CONT_FB: J15.4, R127.1; also elsewhere on the board
/PSU_SW_FAULT: J7.7; also elsewhere on the board
/PSU_SW_PGOOD: J7.6; also elsewhere on the board
/RS485_A: J12.3; also elsewhere on the board
/RS485_B: J12.4; also elsewhere on the board
/SCL: J7.8; also elsewhere on the board
/SDA: J7.4; also elsewhere on the board
/SOURCE_OV: R33.2; also elsewhere on the board
/SW_ARM: C56.1, R113.2, R119.2, U12.6 (3A)
/SW_ARM_BUF: U12.2 (3Y); also elsewhere on the board
/SW_COMPUTE: C55.1, R112.2, R118.2, U12.1 (1A)
/SW_COMPUTE_BUF: U12.7 (1Y); also elsewhere on the board
/SW_REMOTE_ARM: C58.1, R115.2, R121.2, U13.1 (1A)
/SW_REMOTE_ARM_BUF: U13.7 (1Y); also elsewhere on the board
/SW_REMOTE_DISARM: C59.1, R116.2, R122.2, U13.6 (3A)
/SW_REMOTE_DISARM_BUF: U13.2 (3Y); also elsewhere on the board
/SW_RST_FAULT: C57.1, R114.2, R120.2, U12.3 (2A)
/SW_RST_FAULT_BUF: U12.5 (2Y); also elsewhere on the board
/THERM_0: D36.1 (K), J17.2, R71.1; also elsewhere on the board
/THERM_1: D35.1 (K), J16.2, R70.1; also elsewhere on the board
/THERM_2: R69.1, TH1.1; also elsewhere on the board
/V_BUS: J13.4, J14.1
/V_BUS_DIV: C43.1, R80.2, R88.1; also elsewhere on the board
/V_BUS_POS: J18.4, R92.2; also elsewhere on the board
/V_NEG: J13.1, J13.2, K2.3 (N.O.)
/V_SENSE_NEG: C43.2, C44.2, J18.1, J18.3, R80.1, R81.1; also elsewhere on the board
/V_SOURCE: J13.3, K2.4 (N.C.)
/V_SOURCE_DIV: C44.1, R81.2, R89.1; also elsewhere on the board
/V_SOURCE_POS: J18.2, R101.2; also elsewhere on the board
GND: C13.2, C14.1, C15.1, C16.1, C18.1, C20.2, C21.2, C50.2, C51.2, C55.2, C56.2, C57.2, C58.2, C59.2, C60.1, C62.2, D5.1 (K), D6.1 (K), D7.1 (K), D8.1 (K), D9.1 (K), D11.1 (K), D13.1 (K), D14.1 (K), D15.1 (K), D16.1 (K), D17.1 (K), D18.1 (K), D20.1 (K), D21.1 (K), D23.1 (K), D30.2 (A), D31.2 (A), D32.2 (A), D33.2 (A), D34.2 (A), D37.2 (A), J1.1, J3.1, J4.1, J5.1, J6.1, J6.2, J6.3, J7.1, J7.2, J8.1, J8.2, J12.1, J21.1, NT1.2, Q1.2 (E), Q10.2 (E), Q14.2 (E), R6.1, R56.1, R103.1, R112.1, R113.1, R114.1, R115.1, R116.1, R123.1, R127.2, TP2.1, U5.2 (GND), U7.2 (GND_1), U7.4 (GND_2), U8.2 (GND), U12.4 (GND), U13.4 (GND); also elsewhere on the board
GNDA: C52.2, C54.2, C63.2, C64.1, D35.2 (A), D36.2 (A), J16.1, J17.1, NT1.1, TH1.2, TP3.1, U15.1 (VREF), U15.2 (VSS); also elsewhere on the board
unnamed: D5.2 (A), R5.1
unnamed: D6.2 (A), R9.1
unnamed: D7.2 (A), R18.1
unnamed: D8.2 (A), R27.1
unnamed: D9.2 (A), R28.1
unnamed: D11.2 (A), R30.1
unnamed: D13.2 (A), R33.1
unnamed: D14.2 (A), R34.1
unnamed: D15.2 (A), R35.1
unnamed: D16.2 (A), R39.1
unnamed: D17.2 (A), R41.1
unnamed: D18.2 (A), R42.1
unnamed: D19.2 (A), R43.1
unnamed: D19.1 (K), D24.1 (K), K1.5 (COIL_2), Q10.3 (C)
unnamed: D20.2 (A), R46.1
unnamed: D21.2 (A), R50.1, U5.5 (ST)
unnamed: D22.2 (A), D24.2 (A)
unnamed: D23.2 (A), R51.1
unnamed: D25.2 (A), R68.1
unnamed: D25.1 (K), D28.1 (K), K2.5 (COIL_2), Q14.3 (C)
unnamed: D26.2 (A), D28.2 (A)
unnamed: D30.1 (K), J20.4, R118.1
unnamed: D31.1 (K), J20.5, R119.1
unnamed: D32.1 (K), J20.6, R120.1
unnamed: D33.1 (K), J21.5, R121.1
unnamed: D34.1 (K), J21.6, R122.1
unnamed: D37.1 (K), J19.2, R125.1
unnamed: J2.1, U1.3
unnamed: J2.2, U1.4
unnamed: J15.3, R128.1
unnamed: J19.1, R129.2
unnamed: J20.1, R130.2
unnamed: J20.2, R131.2
unnamed: J20.3, R132.2
unnamed: J21.2, R126.2
unnamed: J21.3, R133.2
unnamed: K1.3 (NO), K2.1 (COM)
unnamed: Q1.1 (B), R6.2, R7.2
unnamed: Q1.3 (C), U1.2
unnamed: Q10.1 (B), R55.2, R56.2
unnamed: Q14.1 (B), R102.2, R103.2
unnamed: R8.2, U1.1
unnamed: R88.2, R92.1
unnamed: R89.2, R101.1
unnamed: R53.2, U5.3 (~CE), U8.5 (ST)
unnamed: C53.1, R110.1, U15.5 (VIM)
unnamed: C53.2, R117.1, U15.4 (VIP)

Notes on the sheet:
COMPARATORS
AUX OUTPUTS
CONNECTORS
MOUNTING
DIVIDERS
SWITCH INPUTS
ESTOP OUT
THERMISTORS
3.3V LDO
MISC TEST POINTS
POWER OR
MCU
MISC LEDS
FPGA
COIL DRIVER
DUMP/ PRECHARGE

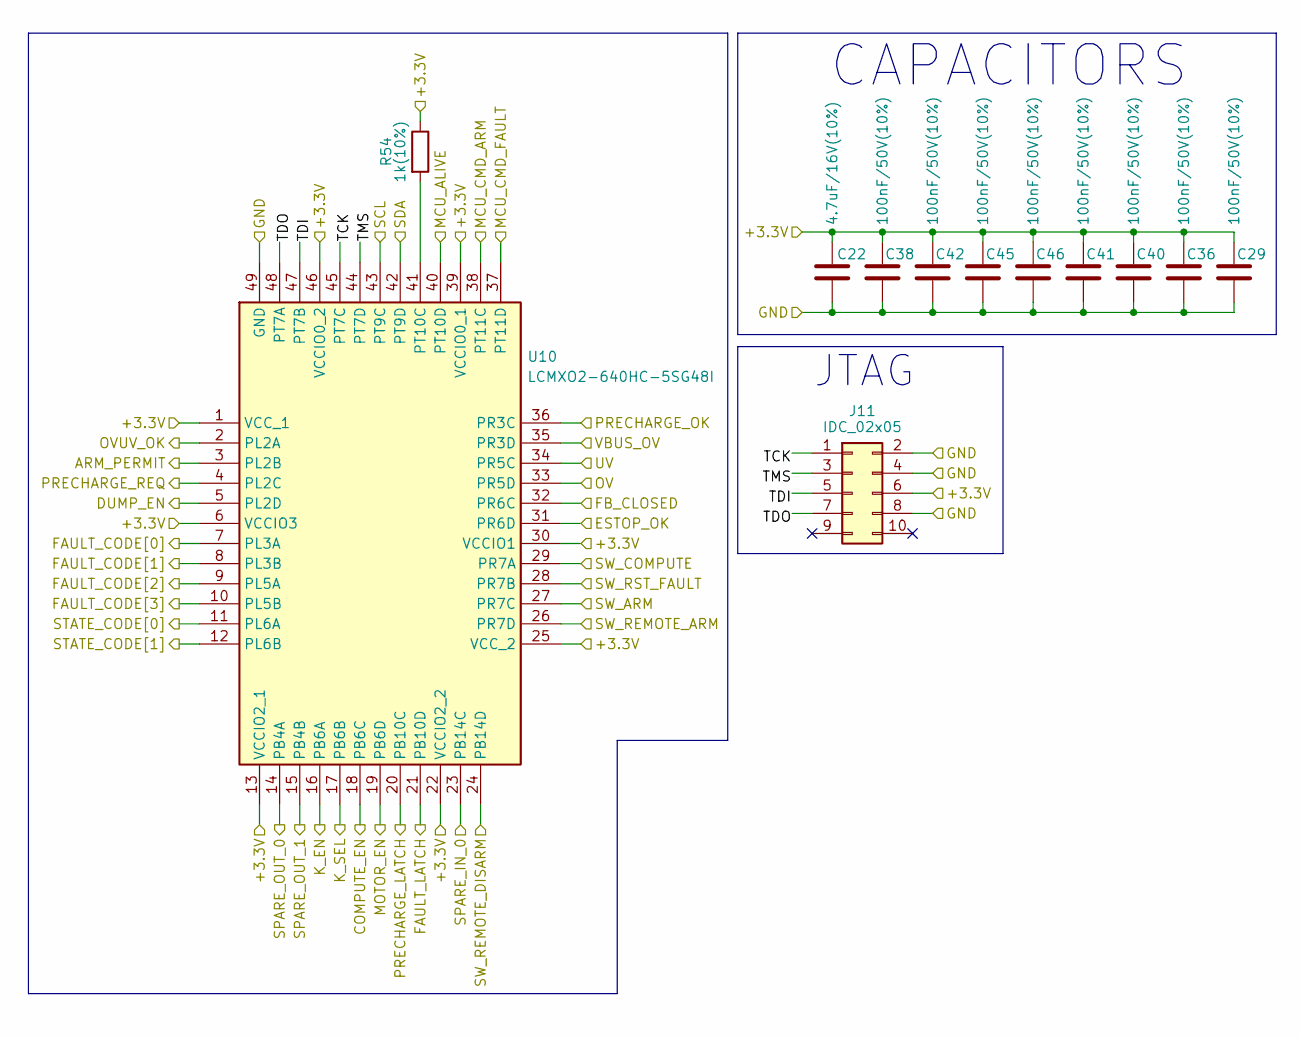
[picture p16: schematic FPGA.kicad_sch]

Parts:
C22: 4.7uF/16V(10%); C_0805_2012Metric
C29, C36, C38, C40, C41, C42, C45, C46: 100nF/50V(10%); C_0402_1005Metric
J11: IDC_02x05; IDC-Header_2x05_P2.54mm_Vertical
R54: 1k(10%); R_0402_1005Metric
U10: LCMXO2-640HC-5SG48I; QFN50P700X700X100-49N-D; Mouser Part Number 842-MXO2640HC5SG48I

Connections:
+3.3V: C22.1, C29.2, C36.2, C38.2, C40.2, C41.2, C42.2, C45.2, C46.2, J11.6, R54.1, U10.1 (VCC_1), U10.6 (VCCIO3), U10.13 (VCCIO2_1), U10.22 (VCCIO2_2), U10.25 (VCC_2), U10.30 (VCCIO1), U10.39 (VCCIO0_1), U10.46 (VCCIO0_2); also elsewhere on the board
/ARM_PERMIT: U10.3 (PL2B)
/BUS_OV: U10.35 (PR3D); also elsewhere on the board
/COMPUTE_EN: U10.18 (PB6C); also elsewhere on the board
/DUMP_EN: U10.5 (PL2D)
/ESTOP_OK_BUF: U10.31 (PR6D); also elsewhere on the board
/FAULT_LATCH: U10.21 (PB10D); also elsewhere on the board
/FPGA/PRECHARGE_REQ: U10.4 (PL2C)
/FPGA/SPARE_IN_0: U10.23 (PB14C)
/FPGA/TCK: J11.1, U10.45 (PT7C)
/FPGA/TDI: J11.5, U10.47 (PT7B)
/FPGA/TDO: J11.7, U10.48 (PT7A)
/FPGA/TMS: J11.3, U10.44 (PT7D)
/FPGA_FC_0: U10.7 (PL3A); also elsewhere on the board
/FPGA_FC_1: U10.8 (PL3B); also elsewhere on the board
/FPGA_FC_2: U10.9 (PL5A); also elsewhere on the board
/FPGA_FC_3: U10.10 (PL5B); also elsewhere on the board
/FPGA_SC_0: U10.11 (PL6A); also elsewhere on the board
/FPGA_SC_1: U10.12 (PL6B); also elsewhere on the board
/FPGA_SPARE_OUT_0: U10.14 (PB4A); also elsewhere on the board
/FPGA_SPARE_OUT_1: U10.15 (PB4B); also elsewhere on the board
/K_EN: U10.16 (PB6A); also elsewhere on the board
/K_SEL: U10.17 (PB6B); also elsewhere on the board
/MCU_ALIVE: U10.40 (PT10D); also elsewhere on the board
/MCU_CMD_ARM: U10.38 (PT11C); also elsewhere on the board
/MCU_CMD_FAULT: U10.37 (PT11D); also elsewhere on the board
/MOTOR_CONT_EN: U10.19 (PB6D); also elsewhere on the board
/MOTOR_CONT_FB: U10.32 (PR6C); also elsewhere on the board
/OVUV_OK: U10.2 (PL2A)
/PRECHARGE_LATCH: U10.20 (PB10C)
/PRECHARGE_OK: U10.36 (PR3C); also elsewhere on the board
/SCL: U10.43 (PT9C); also elsewhere on the board
/SDA: U10.42 (PT9D); also elsewhere on the board
/SOURCE_OV: U10.33 (PR5D); also elsewhere on the board
/SOURCE_UV: U10.34 (PR5C); also elsewhere on the board
/SW_ARM_BUF: U10.27 (PR7C); also elsewhere on the board
/SW_COMPUTE_BUF: U10.29 (PR7A); also elsewhere on the board
/SW_REMOTE_ARM_BUF: U10.26 (PR7D); also elsewhere on the board
/SW_REMOTE_DISARM_BUF: U10.24 (PB14D); also elsewhere on the board
/SW_RST_FAULT_BUF: U10.28 (PR7B); also elsewhere on the board
GND: C22.2, C29.1, C36.1, C38.1, C40.1, C41.1, C42.1, C45.1, C46.1, J11.2, J11.4, J11.8, U10.49 (GND); also elsewhere on the board
unnamed: R54.2, U10.41 (PT10C)

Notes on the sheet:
JTAG
CAPACITORS

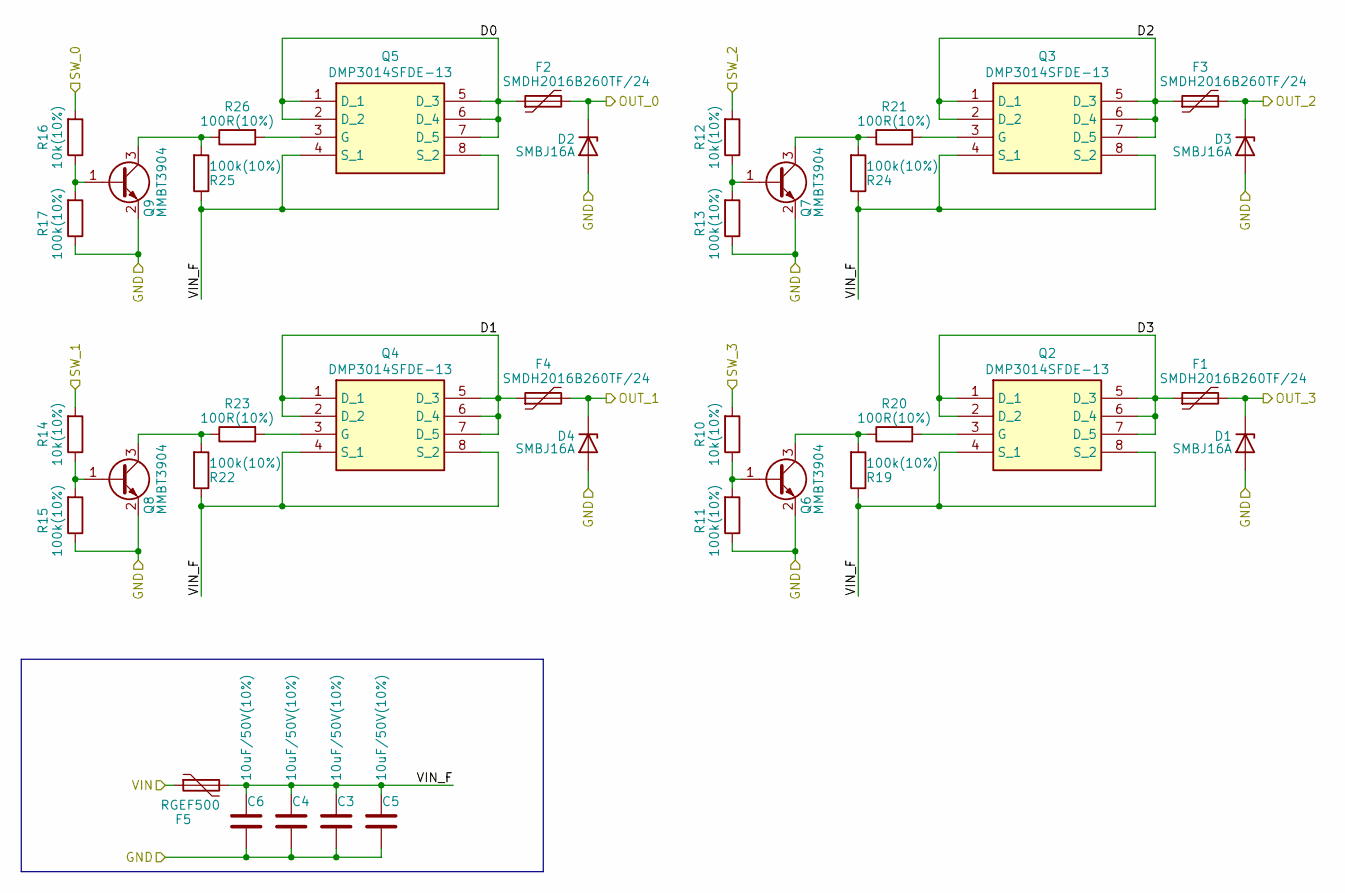
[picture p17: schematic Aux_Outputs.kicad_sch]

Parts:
C3, C4, C5, C6: 10uF/50V(10%); C_1206_3216Metric
D1, D2, D3, D4: SMBJ16A; D_SMB
F1, F2, F3, F4: SMDH2016B260TF/24; FUSC5141X160N
F5: RGEF500
Q2, Q3, Q4, Q5: DMP3014SFDE-13; DMP1022UFDEQ7; Manufacturer_Part_Number DMP3014SFDE-13
Q6, Q7, Q8, Q9: MMBT3904; SOT-23
R10, R12, R14, R16: 10k(10%); R_0402_1005Metric
R11, R13, R15, R17, R19, R22, R24, R25: 100k(10%); R_0402_1005Metric
R20, R21, R23, R26: 100R(10%); R_0402_1005Metric

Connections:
12V_SW: F5.1; also elsewhere on the board
/AUX_SW_0: R16.2; also elsewhere on the board
/AUX_SW_1: R14.2; also elsewhere on the board
/AUX_SW_2: R12.2; also elsewhere on the board
/AUX_SW_3: R10.2; also elsewhere on the board
/Aux Outputs/D0: F2.1, Q5.1 (D_1), Q5.2 (D_2), Q5.5 (D_3), Q5.6 (D_4), Q5.7 (D_5)
/Aux Outputs/D1: F4.1, Q4.1 (D_1), Q4.2 (D_2), Q4.5 (D_3), Q4.6 (D_4), Q4.7 (D_5)
/Aux Outputs/D2: F3.1, Q3.1 (D_1), Q3.2 (D_2), Q3.5 (D_3), Q3.6 (D_4), Q3.7 (D_5)
/Aux Outputs/D3: F1.1, Q2.1 (D_1), Q2.2 (D_2), Q2.5 (D_3), Q2.6 (D_4), Q2.7 (D_5)
/Aux Outputs/OUT_0: D2.1 (K), F2.2; also elsewhere on the board
/Aux Outputs/OUT_1: D4.1 (K), F4.2; also elsewhere on the board
/Aux Outputs/OUT_2: D3.1 (K), F3.2; also elsewhere on the board
/Aux Outputs/OUT_3: D1.1 (K), F1.2; also elsewhere on the board
/Aux Outputs/VIN_F: C3.1, C4.1, C5.1, C6.1, F5.2, Q2.4 (S_1), Q2.8 (S_2), Q3.4 (S_1), Q3.8 (S_2), Q4.4 (S_1), Q4.8 (S_2), Q5.4 (S_1), Q5.8 (S_2), R19.1, R22.1, R24.1, R25.1
GND: C3.2, C4.2, C5.2, C6.2, D1.2 (A), D2.2 (A), D3.2 (A), D4.2 (A), Q6.2 (E), Q7.2 (E), Q8.2 (E), Q9.2 (E), R11.1, R13.1, R15.1, R17.1; also elsewhere on the board
unnamed: Q2.3 (G), R20.2
unnamed: Q3.3 (G), R21.2
unnamed: Q4.3 (G), R23.2
unnamed: Q5.3 (G), R26.2
unnamed: Q6.1 (B), R10.1, R11.2
unnamed: Q6.3 (C), R19.2, R20.1
unnamed: Q7.1 (B), R12.1, R13.2
unnamed: Q7.3 (C), R21.1, R24.2
unnamed: Q8.1 (B), R14.1, R15.2
unnamed: Q8.3 (C), R22.2, R23.1
unnamed: Q9.1 (B), R16.1, R17.2
unnamed: Q9.3 (C), R25.2, R26.1

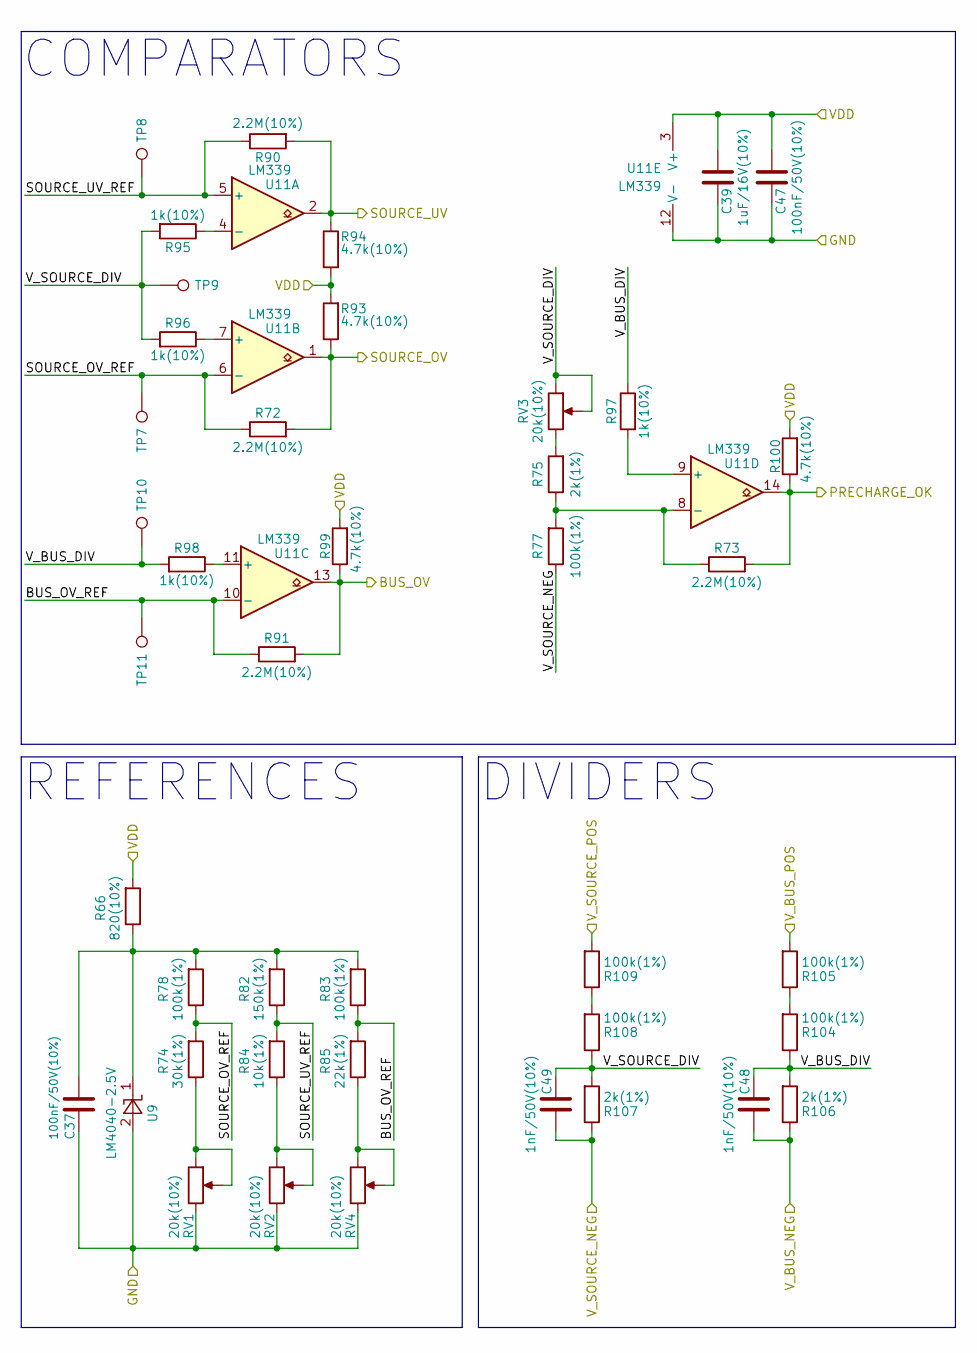
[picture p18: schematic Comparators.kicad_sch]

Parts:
C37, C47: 100nF/50V(10%); C_0402_1005Metric
C39: 1uF/16V(10%); C_0603_1608Metric
C48, C49: 1nF/50V(10%); C_0402_1005Metric
R66: 820(10%); R_0402_1005Metric
R72, R73, R90, R91: 2.2M(10%); R_0402_1005Metric
R74: 30k(1%); R_0402_1005Metric
R75, R106, R107: 2k(1%); R_0402_1005Metric
R77, R78, R83: 100k(1%); R_0402_1005Metric
R82: 150k(1%); R_0402_1005Metric
R84: 10k(1%); R_0402_1005Metric
R85: 22k(1%); R_0402_1005Metric
R93, R94, R99, R100: 4.7k(10%); R_0402_1005Metric
R95, R96, R97, R98: 1k(10%); R_0402_1005Metric
R104, R105, R108, R109: 100k(1%); R_0603_1608Metric
RV1, RV2, RV3, RV4: 20k(10%); Potentiometer_Bourns_3296Y_Vertical
TP7, TP8, TP9, TP10, TP11: TestPoint; TestPoint_Pad_D1.0mm
U9: LM4040-2.5V; TSOT-23; Part Number LM4040B25FTA
U11: LM339; TSSOP-14_4.4x5mm_P0.65mm

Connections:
+3.3VA: C39.2, C47.1, R66.2, R93.2, R94.2, R99.2, R100.2, U11.3 (V+); also elsewhere on the board
/BUS_OV: R91.2, R99.1, U11.13; also elsewhere on the board
/Comparators/BUS_OV_REF: R83.1, R85.2, R91.1, TP11.1, U11.10 (-)
/Comparators/SOURCE_OV_REF: R72.1, R74.2, R78.1, TP7.1, U11.6 (-)
/Comparators/SOURCE_UV_REF: R82.1, R84.2, R90.1, TP8.1, U11.5 (+)
/Comparators/V_BUS_DIV: C48.1, R97.1, R98.2, R104.1, R106.2, TP10.1
/Comparators/V_SOURCE_DIV: C49.1, R95.2, R96.2, R107.2, R108.1, RV3.1, RV3.2, TP9.1
/PRECHARGE_OK: R73.2, R100.1, U11.14; also elsewhere on the board
/SOURCE_OV: R72.2, R93.1, U11.1; also elsewhere on the board
/SOURCE_UV: R90.2, R94.1, U11.2; also elsewhere on the board
/V_BUS_POS: R105.2; also elsewhere on the board
/V_SENSE_NEG: C48.2, C49.2, R77.1, R106.1, R107.1; also elsewhere on the board
/V_SOURCE_POS: R109.2; also elsewhere on the board
GNDA: C37.2, C39.1, C47.2, RV1.3, RV2.3, RV4.3, U9.2 (A), U11.12 (V-); also elsewhere on the board
unnamed: R74.1, RV1.1, RV1.2
unnamed: R75.2, RV3.3
unnamed: R84.1, RV2.1, RV2.2
unnamed: R85.1, RV4.1, RV4.2
unnamed: R104.2, R105.1
unnamed: R108.2, R109.1
unnamed: C37.1, R66.1, R78.2, R82.2, R83.2, U9.1 (K)
unnamed: R95.1, U11.4 (-)
unnamed: R96.1, U11.7 (+)
unnamed: R98.1, U11.11 (+)
unnamed: R97.2, U11.9 (+)
unnamed: R73.1, R75.1, R77.2, U11.8 (-)

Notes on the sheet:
COMPARATORS
REFERENCES
DIVIDERS

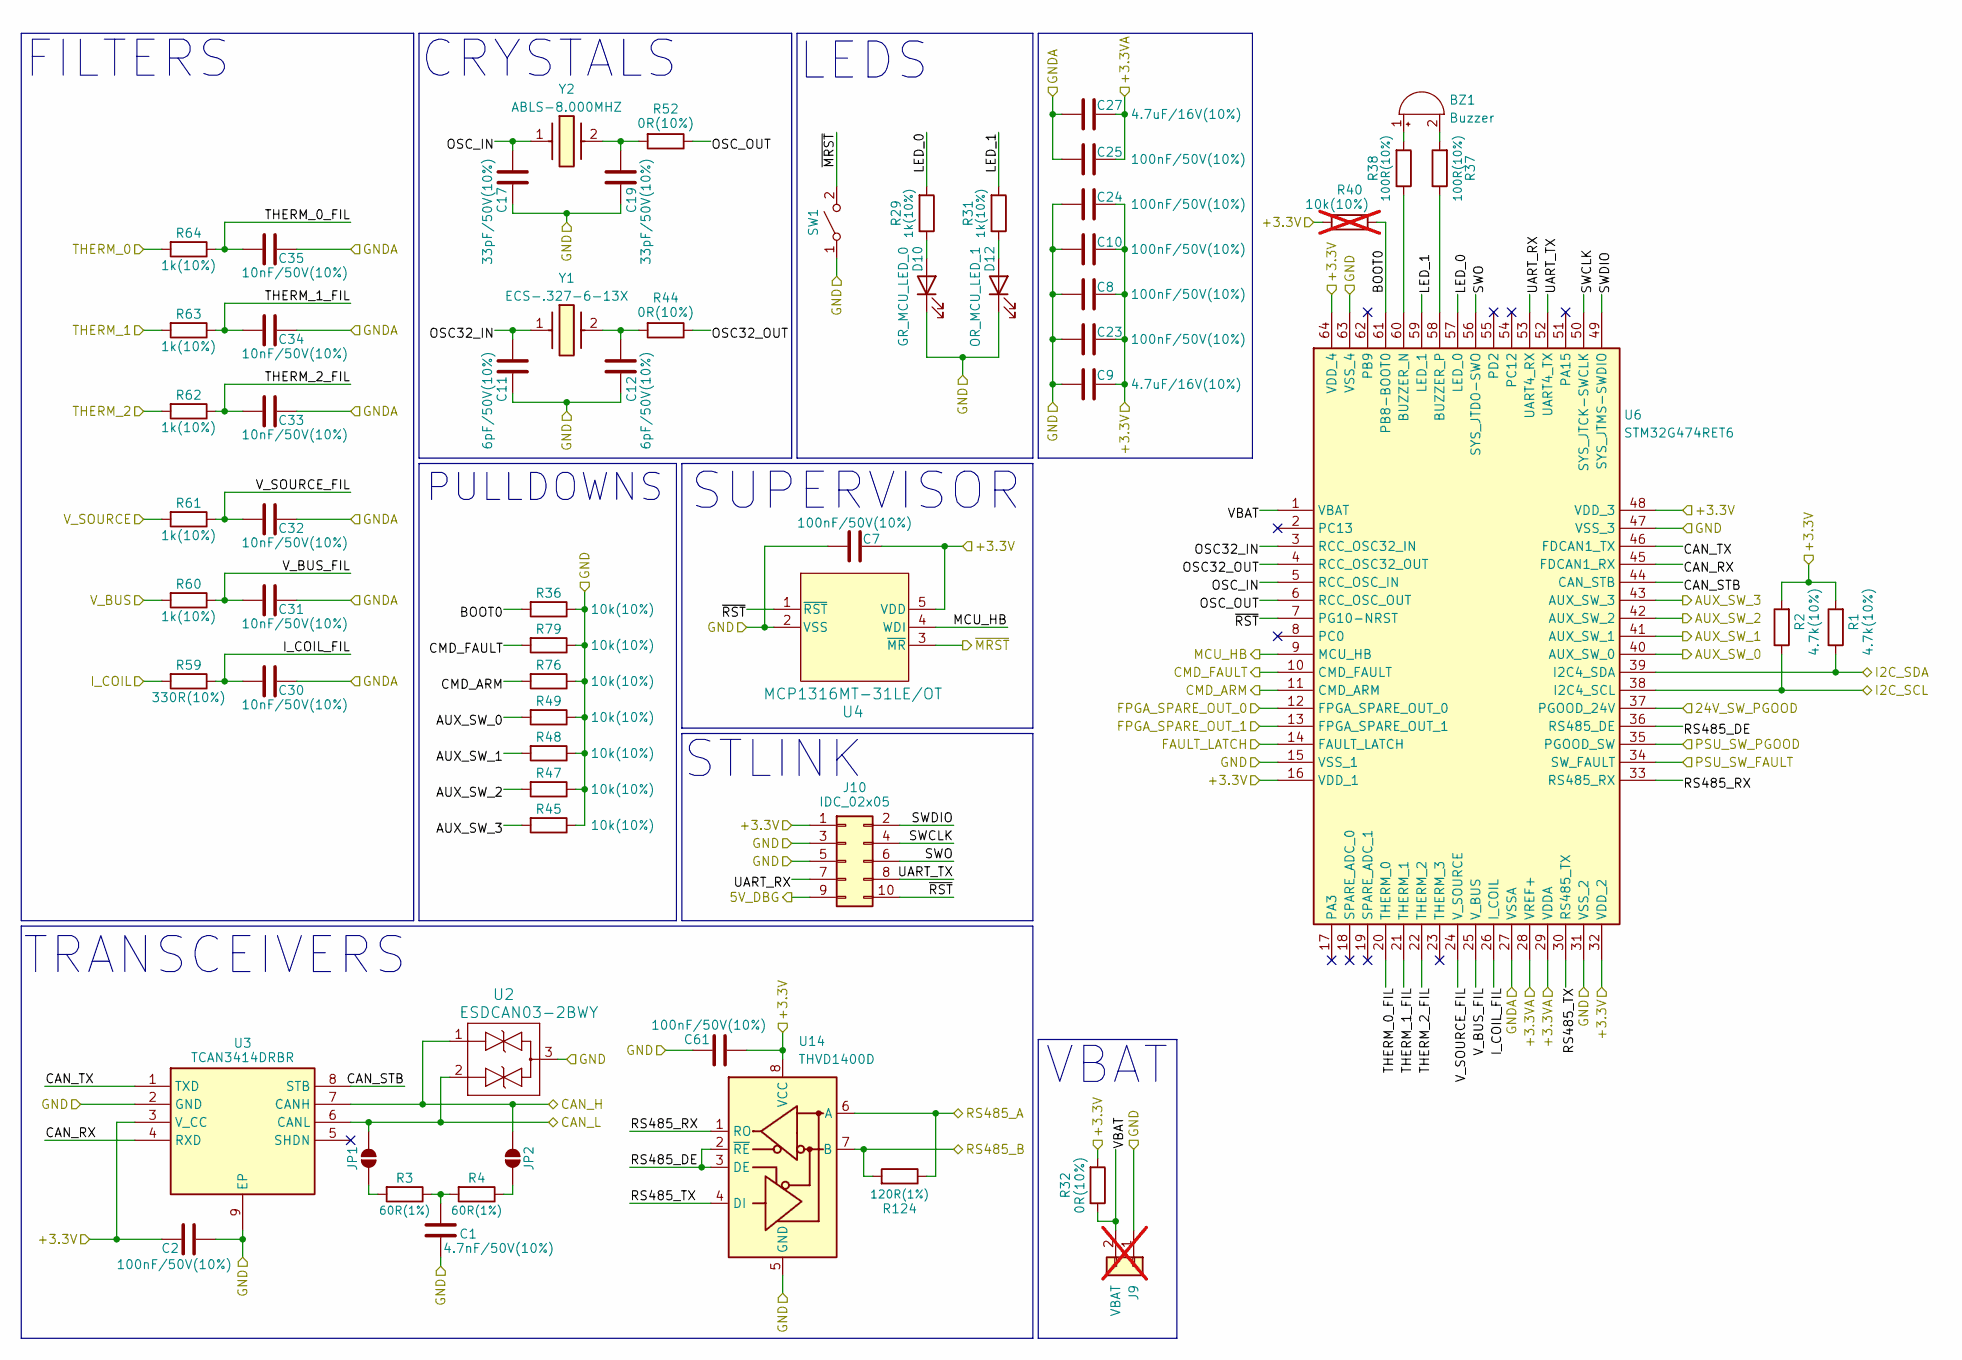
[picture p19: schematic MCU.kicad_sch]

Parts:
BZ1: Buzzer; C_Radial_D10.0mm_H12.5mm_P5.00mm
C1: 4.7nF/50V(10%); C_0402_1005Metric
C2, C7, C8, C10, C23, C24, C25, C61: 100nF/50V(10%); C_0402_1005Metric
C9, C27: 4.7uF/16V(10%); C_0805_2012Metric
C11, C12: 6pF/50V(10%); C_0402_1005Metric
C17, C19: 33pF/50V(10%); C_0402_1005Metric
C30, C31, C32, C33, C34, C35: 10nF/50V(10%); C_0402_1005Metric
D10: GR_MCU_LED_0; D_0805_2012Metric
D12: OR_MCU_LED_1; D_0805_2012Metric
J9: VBAT; PinHeader_1x02_P2.54mm_Vertical; Part Number 1-0201FBV0T; not fitted
J10: IDC_02x05; IDC-Header_2x05_P2.54mm_Vertical
JP1, JP2: SolderJumper_2_Open; SolderJumper-2_P1.3mm_Open_Pad1.0x1.5mm
R1, R2: 4.7k(10%); R_0402_1005Metric
R3, R4: 60R(1%); R_0402_1005Metric
R29, R31, R60, R61, R62, R63, R64: 1k(10%); R_0402_1005Metric
R32, R44, R52: 0R(10%); R_0402_1005Metric
R36, R45, R47, R48, R49, R76, R79: 10k(10%); R_0402_1005Metric
R37, R38: 100R(10%); R_0402_1005Metric
R40: 10k(10%); R_0402_1005Metric; not fitted
R59: 330R(10%); R_0402_1005Metric
R124: 120R(1%); R_0402_1005Metric
SW1: SW_SPST; SW_SPST_TS-1088-xR020
U2: ESDCAN03-2BWY; SOT-323_SC-70
U3: TCAN3414DRBR; VSON-8-1EP_3x3mm_P0.65mm_EP1.6x2.4mm; Mouser Part Number 595-TCAN3414DRBR
U4: MCP1316MT-31LE/OT; SOT-23-5
U6: STM32G474RET6; LQFP-64_10x10mm_P0.5mm
U14: THVD1400D; SOIC-8_3.9x4.9mm_P1.27mm
Y1: ECS-.327-6-13X; Crystal_DS26_D2.0mm_L6.0mm_Vertical; Mouser Part Number 520-ECS327-6-13-X
Y2: ABLS-8.000MHZ; ABLS8000MHZ20D3HT; Mouser Part Number 815-LS8000MHZ20D3HT

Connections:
+3.3V: C2.2, C7.1, C8.2, C9.1, C10.2, C23.2, C24.2, C61.1, J10.1, R1.2, R2.2, R32.2, R40.1, U3.3 (V_CC), U4.5 (VDD), U6.16 (VDD_1), U6.32 (VDD_2), U6.48 (VDD_3), U6.64 (VDD_4), U14.8 (VCC); also elsewhere on the board
+3.3VA: C25.2, C27.1, U6.28 (VREF+), U6.29 (VDDA); also elsewhere on the board
/5V_DBG: J10.9; also elsewhere on the board
/24V_SW_PGOOD: U6.37 (PGOOD_24V); also elsewhere on the board
/AUX_SW_0: R49.2, U6.40 (AUX_SW_0); also elsewhere on the board
/AUX_SW_1: R48.2, U6.41 (AUX_SW_1); also elsewhere on the board
/AUX_SW_2: R47.2, U6.42 (AUX_SW_2); also elsewhere on the board
/AUX_SW_3: R45.2, U6.43 (AUX_SW_3); also elsewhere on the board
/CAN_H: JP2.2 (B), U2.1, U3.7 (CANH); also elsewhere on the board
/CAN_L: JP1.2 (B), U2.2, U3.6 (CANL); also elsewhere on the board
/FAULT_LATCH: U6.14 (FAULT_LATCH); also elsewhere on the board
/FPGA_SPARE_OUT_0: U6.12 (FPGA_SPARE_OUT_0); also elsewhere on the board
/FPGA_SPARE_OUT_1: U6.13 (FPGA_SPARE_OUT_1); also elsewhere on the board
/I_COIL: R59.2; also elsewhere on the board
/MCU/BOOT0: R36.2, R40.2, U6.61 (PB8-BOOT0)
/MCU/CAN_RX: U3.4 (RXD), U6.45 (FDCAN1_RX)
/MCU/CAN_STB: U3.8 (STB), U6.44 (CAN_STB)
/MCU/CAN_TX: U3.1 (TXD), U6.46 (FDCAN1_TX)
/MCU/I_COIL_FIL: C30.1, R59.1, U6.26 (I_COIL)
/MCU/LED_0: R29.2, U6.57 (LED_0)
/MCU/LED_1: R31.2, U6.59 (LED_1)
/MCU/OSC32_IN: C11.2, U6.3 (RCC_OSC32_IN), Y1.1
/MCU/OSC32_OUT: R44.1, U6.4 (RCC_OSC32_OUT)
/MCU/OSC_IN: C17.2, U6.5 (RCC_OSC_IN), Y2.1
/MCU/OSC_OUT: R52.1, U6.6 (RCC_OSC_OUT)
/MCU/RS485_DE: U6.36 (RS485_DE), U14.2 (~RE), U14.3 (DE)
/MCU/RS485_RX: U6.33 (RS485_RX), U14.1 (RO)
/MCU/RS485_TX: U6.30 (RS485_TX), U14.4 (DI)
/MCU/SWCLK: J10.4, U6.50 (SYS_JTCK-SWCLK)
/MCU/SWDIO: J10.2, U6.49 (SYS_JTMS-SWDIO)
/MCU/SWO: J10.6, U6.56 (SYS_JTDO-SWO)
/MCU/THERM_0_FIL: C35.1, R64.1, U6.20 (THERM_0)
/MCU/THERM_1_FIL: C34.1, R63.1, U6.21 (THERM_1)
/MCU/THERM_2_FIL: C33.1, R62.1, U6.22 (THERM_2)
/MCU/UART_RX: J10.7, U6.53 (UART4_RX)
/MCU/UART_TX: J10.8, U6.52 (UART4_TX)
/MCU/VBAT: J9.2, R32.1, U6.1 (VBAT)
/MCU/V_BUS_FIL: C31.1, R60.1, U6.25 (V_BUS)
/MCU/V_SOURCE_FIL: C32.1, R61.1, U6.24 (V_SOURCE)
/MCU/~RST: J10.10, U4.1 (~RST), U6.7 (PG10-NRST)
/MCU_ALIVE: U4.4 (WDI), U6.9 (MCU_HB); also elsewhere on the board
/MCU_CMD_ARM: R76.2, U6.11 (CMD_ARM); also elsewhere on the board
/MCU_CMD_FAULT: R79.2, U6.10 (CMD_FAULT); also elsewhere on the board
/MCU_NRST: SW1.2 (B), U4.3 (~MR)
/PSU_SW_FAULT: U6.34 (SW_FAULT); also elsewhere on the board
/PSU_SW_PGOOD: U6.35 (PGOOD_SW); also elsewhere on the board
/RS485_A: R124.1, U14.6 (A); also elsewhere on the board
/RS485_B: R124.2, U14.7 (B); also elsewhere on the board
/SCL: R2.1, U6.38 (I2C4_SCL); also elsewhere on the board
/SDA: R1.1, U6.39 (I2C4_SDA); also elsewhere on the board
/THERM_0: R64.2; also elsewhere on the board
/THERM_1: R63.2; also elsewhere on the board
/THERM_2: R62.2; also elsewhere on the board
/V_BUS_DIV: R60.2; also elsewhere on the board
/V_SOURCE_DIV: R61.2; also elsewhere on the board
GND: C1.1, C2.1, C7.2, C8.1, C9.2, C10.1, C11.1, C12.1, C17.1, C19.1, C23.1, C24.1, C61.2, D10.1 (K), D12.1 (K), J9.1, J10.3, J10.5, R36.1, R45.1, R47.1, R48.1, R49.1, R76.1, R79.1, SW1.1 (A), U2.3, U3.2 (GND), U3.9 (EP), U4.2 (VSS), U6.15 (VSS_1), U6.31 (VSS_2), U6.47 (VSS_3), U6.63 (VSS_4), U14.5 (GND); also elsewhere on the board
GNDA: C25.1, C27.2, C30.2, C31.2, C32.2, C33.2, C34.2, C35.2, U6.27 (VSSA); also elsewhere on the board
unnamed: BZ1.1 (+), R38.2
unnamed: BZ1.2 (-), R37.2
unnamed: C1.2, R3.1, R4.2
unnamed: C12.2, R44.2, Y1.2
unnamed: C19.2, R52.2, Y2.2
unnamed: D10.2 (A), R29.1
unnamed: D12.2 (A), R31.1
unnamed: JP1.1 (A), R3.2
unnamed: JP2.1 (A), R4.1
unnamed: R38.1, U6.60 (BUZZER_N)
unnamed: R37.1, U6.58 (BUZZER_P)

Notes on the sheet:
TRANSCEIVERS
LEDS
STLINK
SUPERVISOR
CRYSTALS
FILTERS
VBAT
PULLDOWNS

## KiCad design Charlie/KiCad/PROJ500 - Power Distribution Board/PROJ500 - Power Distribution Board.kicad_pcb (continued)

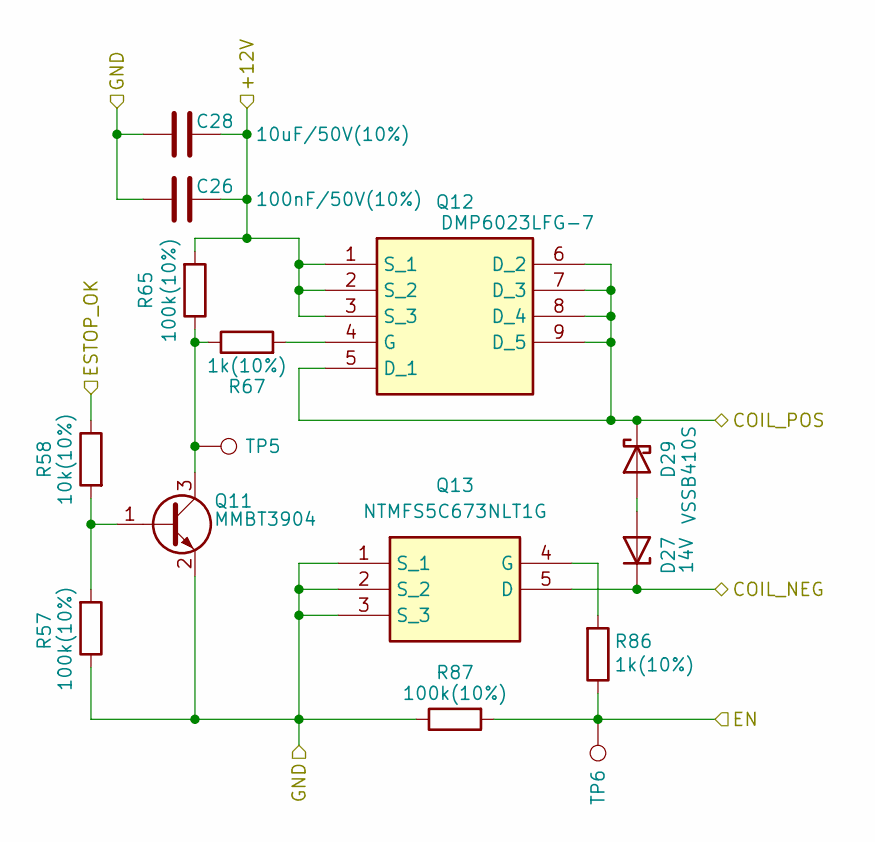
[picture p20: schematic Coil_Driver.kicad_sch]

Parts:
C26: 100nF/50V(10%); C_0402_1005Metric
C28: 10uF/50V(10%); C_1206_3216Metric
D27: 14V; D_SOD-123
D29: VSSB410S; D_SMB
Q11: MMBT3904; SOT-23
Q12: DMP6023LFG-7; DMP4013LFG7; Mouser Part Number 621-DMP6023LFG-7
Q13: NTMFS5C673NLT1G; ONSemi_SO-8FL_488AA; Mouser Part Number 863-NTMFS5C673NLT1G
R57, R65, R87: 100k(10%); R_0402_1005Metric
R58: 10k(10%); R_0402_1005Metric
R67, R86: 1k(10%); R_0402_1005Metric
TP5, TP6: TestPoint; TestPoint_Pad_D1.0mm

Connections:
+12V: C26.1, C28.2, Q12.1 (S_1), Q12.2 (S_2), Q12.3 (S_3), R65.2; also elsewhere on the board
/Coil Driver/COIL_NEG: D27.1 (K), Q13.5 (D); also elsewhere on the board
/ESTOP_OK_BUF: R58.1; also elsewhere on the board
/MOTOR_COIL_POS: D29.1 (K), Q12.5 (D_1), Q12.6 (D_2), Q12.7 (D_3), Q12.8 (D_4), Q12.9 (D_5); also elsewhere on the board
/MOTOR_CONT_EN: R86.1, R87.2, TP6.1; also elsewhere on the board
GND: C26.2, C28.1, Q11.2 (E), Q13.1 (S_1), Q13.2 (S_2), Q13.3 (S_3), R57.1, R87.1; also elsewhere on the board
unnamed: D27.2 (A), D29.2 (A)
unnamed: Q11.1 (B), R57.2, R58.2
unnamed: Q11.3 (C), R65.1, R67.1, TP5.1
unnamed: Q12.4 (G), R67.2
unnamed: Q13.4 (G), R86.2

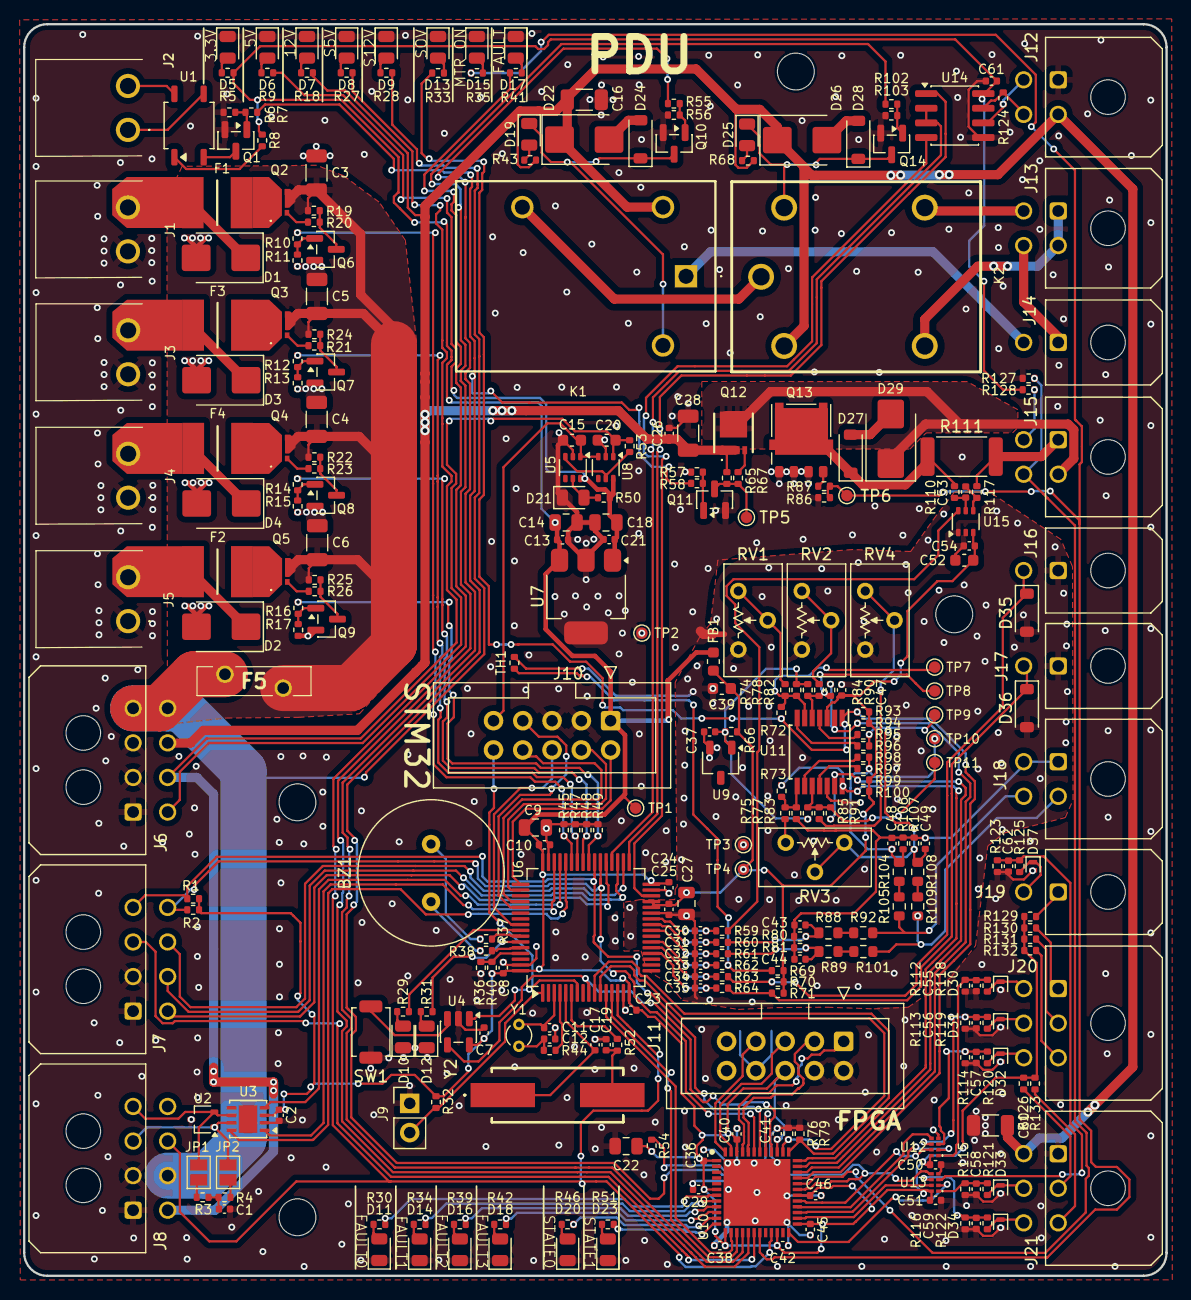
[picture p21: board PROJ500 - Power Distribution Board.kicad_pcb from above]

Board: 2 copper layers, 99.1 x 108.6 mm, 317 parts (0 on the bottom side), 205 nets.

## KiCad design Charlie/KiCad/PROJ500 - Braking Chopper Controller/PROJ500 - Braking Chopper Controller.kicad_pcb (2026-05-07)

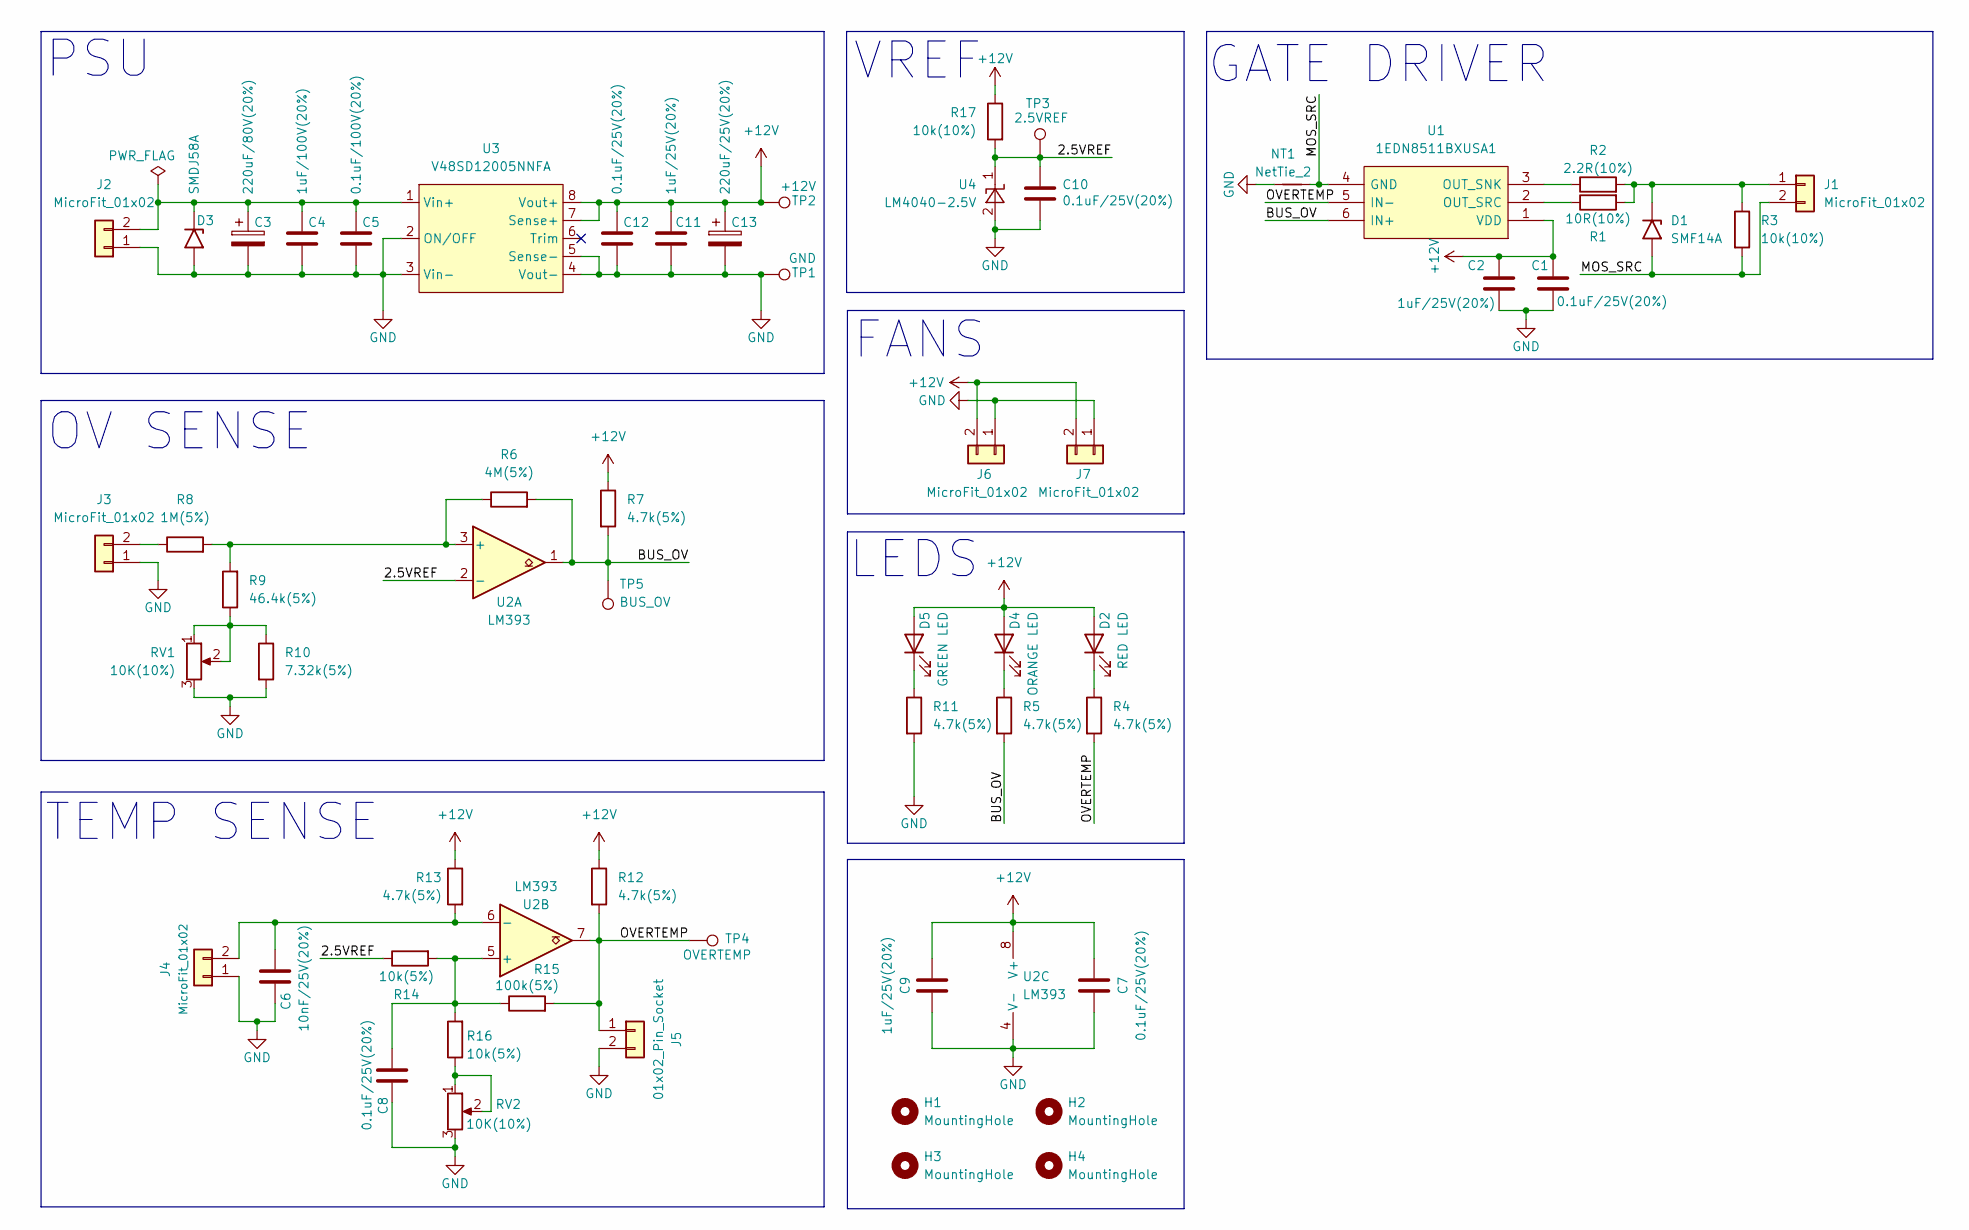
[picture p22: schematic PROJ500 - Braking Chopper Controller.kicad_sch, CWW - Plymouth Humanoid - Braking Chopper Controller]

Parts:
C1, C7, C8, C10, C12: 0.1uF/25V(20%); C_0402_1005Metric
C2, C9, C11: 1uF/25V(20%); C_0603_1608Metric
C3: 220uF/80V(20%); CP_Radial_D12.5mm_P5.00mm
C4: 1uF/100V(20%); C_0603_1608Metric
C5: 0.1uF/100V(20%); C_0603_1608Metric
C6: 10nF/25V(20%); C_0402_1005Metric
C13: 220uF/25V(20%); CP_Radial_D12.5mm_P5.00mm
D1: SMF14A; D_SMF
D2: RED LED; LED_D5.0mm
D3: SMDJ58A; D_SMC
D4: ORANGE LED; LED_D5.0mm
D5: GREEN LED; LED_D5.0mm
H1, H2, H3, H4: MountingHole; MountingHole_3.2mm_M3
J1, J2, J3, J4, J6, J7: MicroFit_01x02; Molex_Micro-Fit_3.0_43650-0215_1x02_P3.00mm_Vertical
J5: 01x02_Pin_Socket; PinHeader_1x02_P2.54mm_Vertical
NT1: NetTie_2; NetTie-2_SMD_Pad0.5mm
R1: 10R(10%); R_0402_1005Metric
R2: 2.2R(10%); R_0402_1005Metric
R3, R17: 10k(10%); R_0402_1005Metric
R4, R5, R7, R11, R12, R13: 4.7k(5%); R_0402_1005Metric
R6: 4M(5%); R_0402_1005Metric
R8: 1M(5%); R_0603_1608Metric
R9: 46.4k(5%); R_0402_1005Metric
R10: 7.32k(5%); R_0402_1005Metric
R14, R16: 10k(5%); R_0402_1005Metric
R15: 100k(5%); R_0402_1005Metric
RV1, RV2: 10K(10%); Potentiometer_Bourns_3296W_Vertical
TP1: GND; TestPoint_Pad_D1.5mm
TP2: +12V; TestPoint_Pad_D1.5mm
TP3: 2.5VREF; TestPoint_Pad_D1.5mm
TP4: OVERTEMP; TestPoint_Pad_D1.5mm
TP5: BUS_OV; TestPoint_Pad_D1.5mm
U1: 1EDN8511BXUSA1; SOT95P280X145-6N; Mouser Part Number 726-1EDN8511BXUSA1
U2: LM393; TSSOP-8_4.4x3mm_P0.65mm
U3: V48SD12005NNFA
U4: LM4040-2.5V; SOT-23-3; Part Number LM4040B25FTA

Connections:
+12V: C1.2, C2.1, C7.1, C9.1, C11.1, C12.1, C13.1, D2.2 (A), D4.2 (A), D5.2 (A), J6.2, J7.2, R7.1, R12.1, R13.1, R17.1, TP2.1, U1.1 (VDD), U2.8 (V+), U3.7 (Sense+), U3.8 (Vout+)
/2.5VREF: C10.1, R14.1, R17.2, TP3.1, U2.2 (-), U4.1 (K)
/BUS_OV: R5.2, R6.2, R7.2, TP5.1, U1.6 (IN+), U2.1
/MOS_SRC: D1.2 (A2), J1.2, NT1.2, R3.2, U1.4 (GND)
/OVERTEMP: J5.1, R4.2, R12.2, R15.2, TP4.1, U1.5 (IN-), U2.7
GND: C1.1, C2.2, C3.2, C4.2, C5.2, C6.2, C7.2, C8.2, C9.2, C10.2, C11.2, C12.2, C13.2, D3.2 (A2), J2.1, J3.1, J4.1, J5.2, J6.1, J7.1, NT1.1, R10.2, R11.2, RV1.3, RV2.3, TP1.1, U2.4 (V-), U3.2 (ON/OFF), U3.3 (Vin-), U3.4 (Vout-), U3.5 (Sense-), U4.2 (A)
unnamed: D1.1 (A1), J1.1, R1.2, R2.2, R3.1
unnamed: D2.1 (K), R4.1
unnamed: C3.1, C4.1, C5.1, D3.1 (A1), J2.2, U3.1 (Vin+)
unnamed: D4.1 (K), R5.1
unnamed: D5.1 (K), R11.1
unnamed: J3.2, R8.1
unnamed: C6.1, J4.2, R13.2, U2.6 (-)
unnamed: R9.1, R10.1, RV1.1, RV1.2
unnamed: R16.1, RV2.1, RV2.2
unnamed: R2.1, U1.3 (OUT_SNK)
unnamed: R1.1, U1.2 (OUT_SRC)
unnamed: R6.1, R8.2, R9.2, U2.3 (+)
unnamed: C8.1, R14.2, R15.1, R16.2, U2.5 (+)

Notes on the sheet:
OV SENSE
GATE DRIVER
TEMP SENSE
VREF
LEDS
FANS
PSU

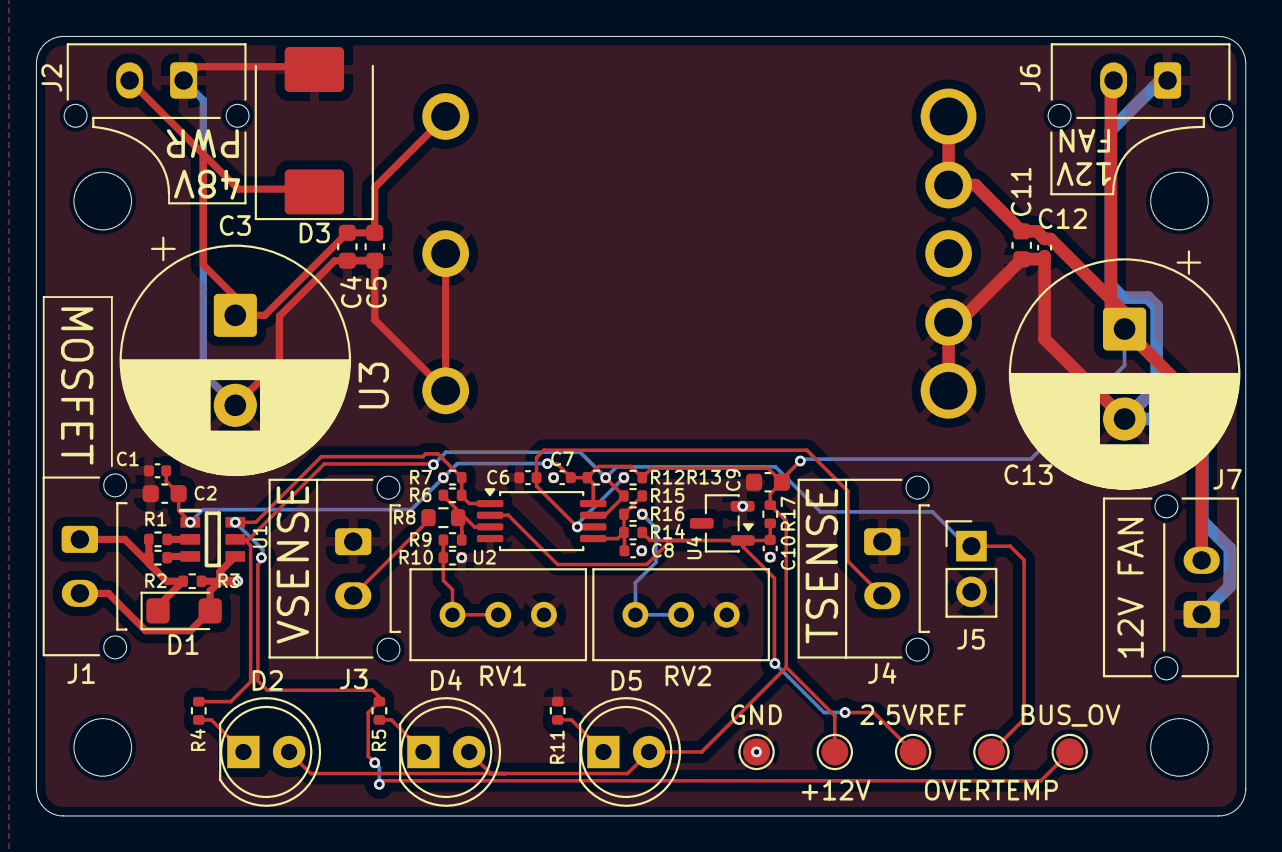
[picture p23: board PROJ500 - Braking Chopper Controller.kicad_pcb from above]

Board: 2 copper layers, 67.2 x 43.3 mm, 58 parts (0 on the bottom side), 19 nets.

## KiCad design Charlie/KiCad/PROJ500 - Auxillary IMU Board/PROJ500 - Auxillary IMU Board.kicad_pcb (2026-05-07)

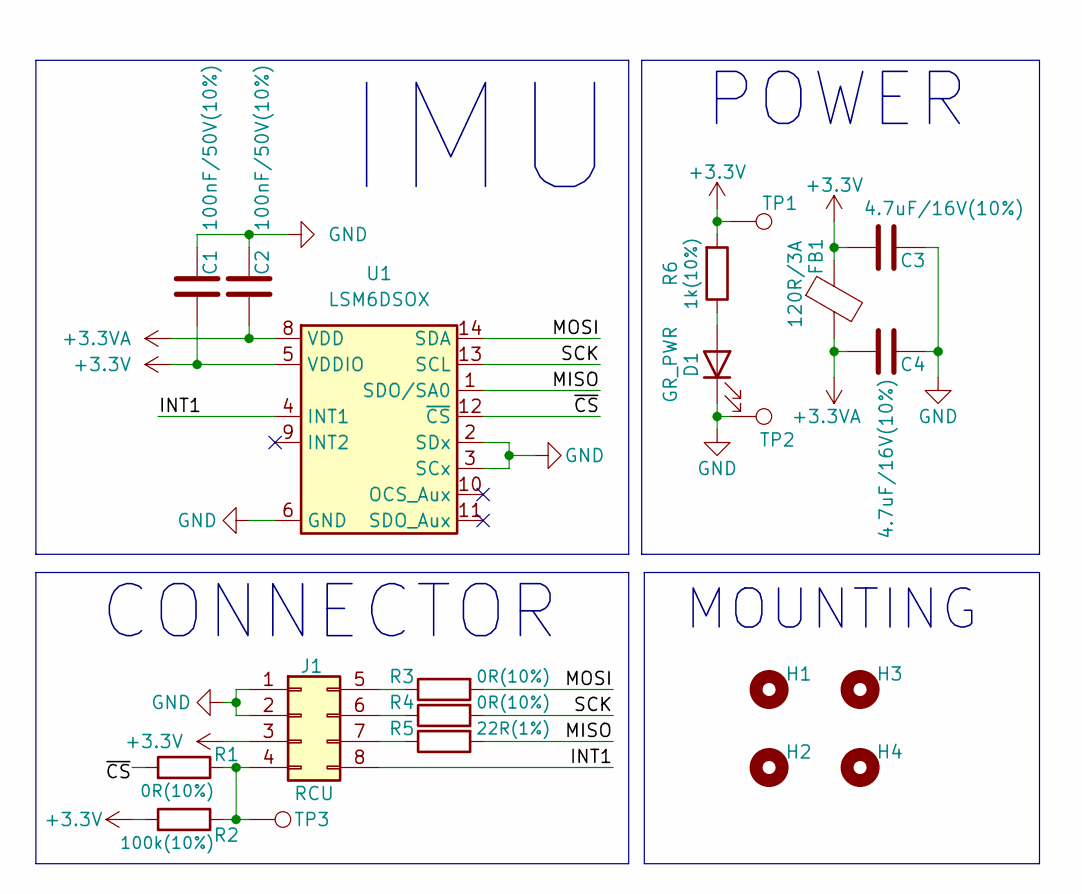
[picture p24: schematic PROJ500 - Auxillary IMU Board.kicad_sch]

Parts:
C1, C2: 100nF/50V(10%); C_0402_1005Metric
C3, C4: 4.7uF/16V(10%); C_0805_2012Metric
D1: GR_PWR; D_0805_2012Metric
FB1: 120R/3A; L_0603_1608Metric
H1, H2, H3, H4: MountingHole; MountingHole_3.2mm_M3
J1: RCU; Molex_Micro-Fit_3.0_43045-0812_2x04_P3.00mm_Vertical
R1, R3, R4: 0R(10%); R_0402_1005Metric
R2: 100k(10%); R_0402_1005Metric
R5: 22R(1%); R_0402_1005Metric
R6: 1k(10%); R_0402_1005Metric
TP1, TP2, TP3: TestPoint; TestPoint_Pad_D1.0mm
U1: LSM6DSOX; ST_LGA-14L_2.5x3.0mm_P0.5mm_4x3

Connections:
+3.3V: C1.1, C3.2, FB1.1, J1.3, R2.2, R6.2, TP1.1, U1.5 (VDDIO)
+3.3VA: C2.1, C4.2, FB1.2, U1.8 (VDD)
/INT1: J1.8, U1.4 (INT1)
/MISO: R5.2, U1.1 (SDO/SA0)
/MOSI: R3.2, U1.14 (SDA)
/SCK: R4.2, U1.13 (SCL)
/~CS: R1.2, U1.12 (~CS)
GND: C1.2, C2.2, C3.1, C4.1, D1.1 (K), J1.1, J1.2, TP2.1, U1.2 (SDx), U1.3 (SCx), U1.6 (GND), U1.7 (GND)
unnamed: D1.2 (A), R6.1
unnamed: J1.4, R1.1, R2.1, TP3.1
unnamed: J1.5, R3.1
unnamed: J1.6, R4.1
unnamed: J1.7, R5.1

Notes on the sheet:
POWER
IMU
MOUNTING
CONNECTOR

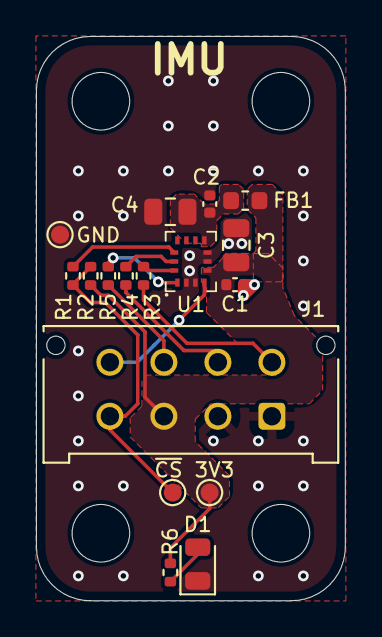
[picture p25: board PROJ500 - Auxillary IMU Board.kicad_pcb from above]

Board: 2 copper layers, 17.2 x 31.4 mm, 21 parts (0 on the bottom side), 13 nets.

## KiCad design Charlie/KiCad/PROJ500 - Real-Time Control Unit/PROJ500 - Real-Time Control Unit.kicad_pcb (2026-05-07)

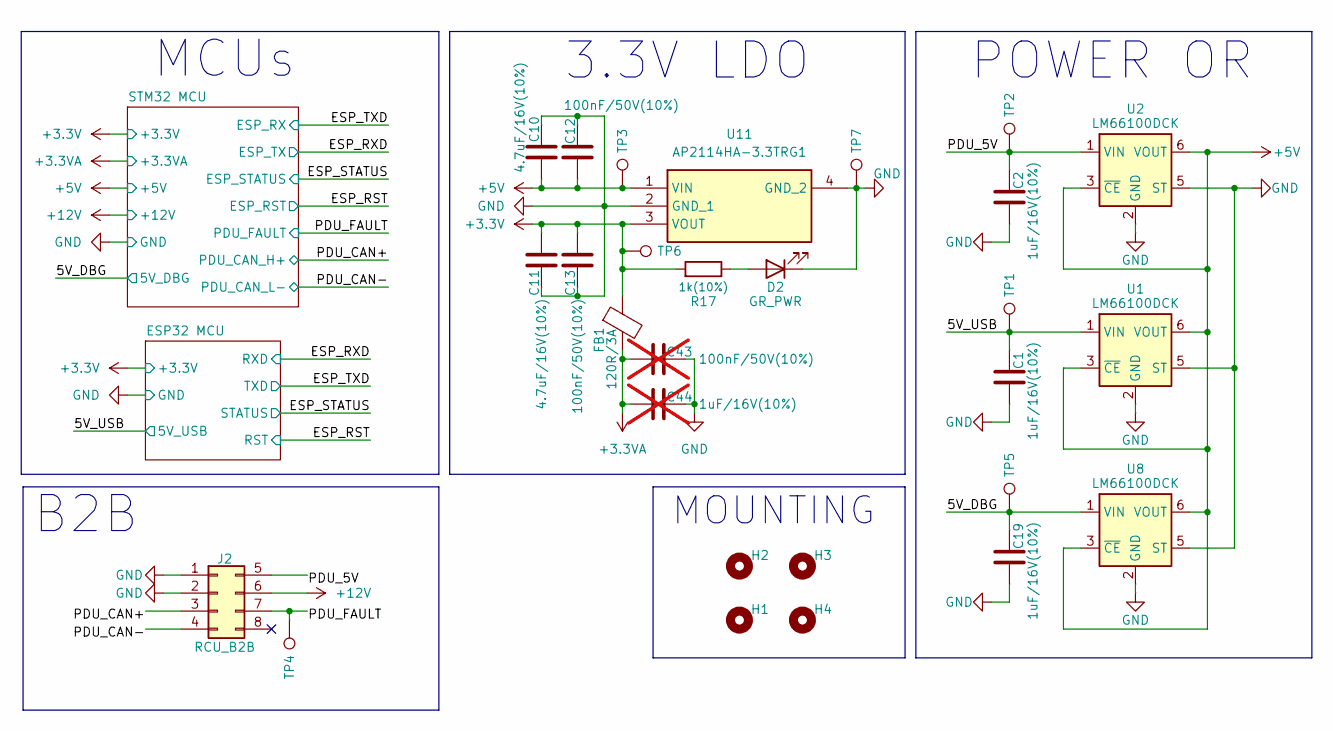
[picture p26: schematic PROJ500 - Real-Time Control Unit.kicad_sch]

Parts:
C1, C2, C19: 1uF/16V(10%); C_0603_1608Metric
C10, C11: 4.7uF/16V(10%); C_0805_2012Metric
C12, C13: 100nF/50V(10%); C_0402_1005Metric
C43: 100nF/50V(10%); C_0402_1005Metric; not fitted
C44: 1uF/16V(10%); C_0603_1608Metric; not fitted
D2: GR_PWR; D_0805_2012Metric
FB1: 120R/3A; L_0603_1608Metric
H1, H2, H3, H4: MountingHole; MountingHole_3.2mm_M3
J2: RCU_B2B; Molex_Micro-Fit_3.0_43045-0800_2x04_P3.00mm_Horizontal
R17: 1k(10%); R_0402_1005Metric
TP1, TP2, TP3, TP4, TP5, TP6, TP7: TestPoint; TestPoint_Pad_D1.0mm
U1, U2, U8: LM66100DCK; SOT-363_SC-70-6
U11: AP2114HA-3.3TRG1; SOT-223; Mouser Part Number 621-AP2114HA-3.3TRG1

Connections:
+3.3V: C11.2, C13.1, FB1.1, R17.2, TP6.1, U11.3 (VOUT); also elsewhere on the board
+3.3VA: C43.1, C44.2, FB1.2; also elsewhere on the board
+5V: C10.2, C12.1, TP3.1, U1.3 (~CE), U1.6 (VOUT), U2.3 (~CE), U2.6 (VOUT), U8.3 (~CE), U8.6 (VOUT), U11.1 (VIN); also elsewhere on the board
+12V: J2.6; also elsewhere on the board
/5V_DBG: C19.1, TP5.1, U8.1 (VIN); also elsewhere on the board
/5V_USB: C1.1, TP1.1, U1.1 (VIN); also elsewhere on the board
/PDU_5V: C2.1, J2.5, TP2.1, U2.1 (VIN)
/PDU_CAN+: J2.3; also elsewhere on the board
/PDU_CAN-: J2.4; also elsewhere on the board
/PDU_FAULT: J2.7, TP4.1; also elsewhere on the board
GND: C1.2, C2.2, C10.1, C11.1, C12.2, C13.2, C19.2, C43.2, C44.1, D2.1 (K), J2.1, J2.2, TP7.1, U1.2 (GND), U1.5 (ST), U2.2 (GND), U2.5 (ST), U8.2 (GND), U8.5 (ST), U11.2 (GND_1), U11.4 (GND_2); also elsewhere on the board
unnamed: D2.2 (A), R17.1

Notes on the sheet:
POWER OR
MCUs
MOUNTING
B2B
3.3V LDO


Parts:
C3: 1uF/16V(10%); C_0603_1608Metric
C4: 100nF/50V(10%); C_0402_1005Metric
C6, C7: 10uF/10V(20%); C_0603_1608Metric
D1: GR_ESP_STATUS; D_0805_2012Metric
J1: USB_C_Receptacle_USB2.0_16P; USB_C_Receptacle_GCT_USB4105-xx-A_16P_TopMnt_Horizontal
Q1: MMBT3904; SOT-23
R1: 1k(10%); R_0402_1005Metric
R2, R3, R4, R8, R9, R18: 10k(10%); R_0402_1005Metric
R5, R6: 5.1k(1%); R_0402_1005Metric
R7: 100k(10%); R_0402_1005Metric
R11, R12: 22R(1%); R_0402_1005Metric
R13, R14: 330R(10%); R_0402_1005Metric
SW1: ESP_BOOT; SW_SPST_TS-1088-xR020
SW3: ESP_EN; SW_SPST_TS-1088-xR020
U3: ESP32-C3-MINI-1U-H4X; ESP32C3MINI1UH4X; Manufacturer_Part_Number ESP32-C3-MINI-1U-H4X
U4: USBLC6-2SC6; SOT-23-6

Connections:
+3.3V: C4.1, C6.1, C7.1, R4.2, R9.2, U3.3 (3V3); also elsewhere on the board
/5V_USB: J1.A4 (VBUS), J1.A9 (VBUS), J1.B4 (VBUS), J1.B9 (VBUS), R3.2, U4.5 (VBUS); also elsewhere on the board
/ESP32 MCU/BOOT0: R4.1, SW1.2 (B), U3.23 (IO9)
/ESP32 MCU/D+: J1.A6 (D+), J1.B6 (D+), U4.3 (I/O2)
/ESP32 MCU/D-: J1.A7 (D-), J1.B7 (D-), U4.1 (I/O1)
/ESP32 MCU/EN: C3.2, Q1.3 (C), R9.1, SW3.2 (B), U3.8 (EN)
/ESP32 MCU/LED: R1.2, U3.16 (IO10)
/ESP32 MCU/USB_D+: R12.1, U3.27 (IO19)
/ESP32 MCU/USB_D-: R11.1, U3.26 (IO18)
/ESP32 MCU/VBUS_SENSE: R2.2, R3.1, U3.18 (IO4)
/ESP_RST: R8.1; also elsewhere on the board
/ESP_RXD: R14.1; also elsewhere on the board
/ESP_STATUS: R18.2, U3.20 (IO6); also elsewhere on the board
/ESP_TXD: R13.1; also elsewhere on the board
GND: C3.1, C4.2, C6.2, C7.2, D1.1 (K), J1.A1 (GND), J1.A12 (GND), J1.B1 (GND), J1.B12 (GND), J1.S1 (SHIELD), Q1.2 (E), R2.1, R5.2, R6.2, R7.1, R18.1, SW1.1 (A), SW3.1 (A), U3.1 (GND_1), U3.2 (GND_2), U3.11 (GND_3), U3.14 (GND_4), U3.36 (GND_5), U3.37 (GND_6), U3.38 (GND_7), U3.39 (GND_8), U3.40 (GND_9), U3.41 (GND_10), U3.42 (GND_11), U3.43 (GND_12), U3.44 (GND_13), U3.45 (GND_14), U3.46 (GND_15), U3.47 (GND_16), U3.48 (GND_17), U3.49 (GND_18), U3.50 (GND_19), U3.51 (GND_20), U3.52 (GND_21), U3.53 (GND_22), U3.54 (GND_23), U3.55 (GND_24), U3.56 (GND_25), U3.57 (GND_26), U3.58 (GND_27), U3.59 (GND_28), U3.60 (GND_29), U3.61 (GND_30), U4.2 (GND); also elsewhere on the board
unnamed: D1.2 (A), R1.1
unnamed: J1.A5 (CC1), R5.1
unnamed: J1.B5 (CC2), R6.1
unnamed: Q1.1 (B), R7.2, R8.2
unnamed: R11.2, U4.6 (I/O1)
unnamed: R12.2, U4.4 (I/O2)
unnamed: R14.2, U3.30 (RXD0)
unnamed: R13.2, U3.31 (TXD0)

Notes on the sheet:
ENABLE
ESP32-C3-MINI-1
USB-C
BOOT & LED


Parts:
BZ1: Buzzer; C_Radial_D10.0mm_H12.5mm_P5.00mm
C5, C9, C15, C20, C21, C22, C24, C25, C27, C28, C38, C41: 100nF/50V(10%); C_0402_1005Metric
C8, C39, C42: 4.7nF/50V(10%); C_0402_1005Metric
C14: 1uF/16V(10%); C_0603_1608Metric
C16, C17: 6pF/50V(10%); C_0402_1005Metric
C18, C23: 4.7uF/16V(10%); C_0805_2012Metric
C26, C30: 2.2uF/10V(10%); C_0603_1608Metric
D3: GR_MCU_LED_0; D_0805_2012Metric
D4: OR_MCU_LED_1; D_0805_2012Metric
F1, F2: 1.95A; FUSC4632X200N
J3: VBAT; PinHeader_1x02_P2.54mm_Vertical; Part Number 1-0201FBV0T; not fitted
J4: EXPANSION_HEADER; IDC-Header_2x08_P2.54mm_Vertical
J5: IDC_02x05; IDC-Header_2x05_P2.54mm_Vertical
J7: IMU1; Molex_Micro-Fit_3.0_43045-0800_2x04_P3.00mm_Horizontal
J8: CAN_MTR_R; Molex_Micro-Fit_3.0_43045-0200_2x01_P3.00mm_Horizontal
J9: CAN_MTR_L; Molex_Micro-Fit_3.0_43045-0200_2x01_P3.00mm_Horizontal
JP1, JP2, JP3, JP4, JP5, JP6: SolderJumper_2_Open; SolderJumper-2_P1.3mm_Open_Pad1.0x1.5mm
R10, R15, R45, R48, R49, R50: 60R(1%); R_0402_1005Metric
R16, R22, R23, R53: 0R(10%); R_0402_1005Metric
R19, R25: 10k(10%); R_0402_1005Metric
R20, R24: 1k(10%); R_0402_1005Metric
R21: 10k(1%); R_0402_1005Metric
R26, R27: 100R(10%); R_0402_1005Metric
R32, R33: 4.7k(10%); R_0402_1005Metric
R51, R52, R54: 22R(1%); R_0402_1005Metric
SW2: SW_SPST; SW_SPST_TS-1088-xR020
TH1: NTC/10K; R_0402_1005Metric
U5, U15, U16: TCAN3414DRBR; VSON-8-1EP_3x3mm_P0.65mm_EP1.6x2.4mm; Mouser Part Number 595-TCAN3414DRBR
U6, U17, U18: ESDCAN03-2BWY; SOT-323_SC-70
U7: LSM6DSOX; ST_LGA-14L_2.5x3.0mm_P0.5mm_4x3
U9: CDC6CEx; Oscillator_SMD_VSON-4_2x1.6mm
U10: MCP1316MT-31LE/OT; SOT-23-5
U12: STM32H723VGT6; LQFP-100_14x14mm_P0.5mm
Y1: ECS-.327-6-13X; Crystal_DS26_D2.0mm_L6.0mm_Vertical; Mouser Part Number 520-ECS327-6-13-X

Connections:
+3.3V: C5.2, C9.1, C14.1, C20.2, C22.1, C23.1, C24.2, C25.2, C27.2, C28.2, C38.2, C41.2, J4.5, J4.6, J5.1, J7.3, R16.2, R32.1, R33.1, U5.3 (V_CC), U7.5 (VDDIO), U9.4 (VDD), U10.5 (VDD), U12.11 (VDD_1), U12.27 (VDD_2), U12.50 (VDD_3), U12.75 (VDD_4), U12.100 (VDD_5), U15.3 (V_CC), U16.3 (V_CC); also elsewhere on the board
+3.3VA: C15.1, C18.1, C21.2, R21.2, U7.8 (VDD), U12.20 (VREF+), U12.21 (VDDA); also elsewhere on the board
+5V: F1.2; also elsewhere on the board
+12V: F2.1; also elsewhere on the board
/5V_DBG: J5.9; also elsewhere on the board
/ESP_RST: U12.96 (ESP_RST); also elsewhere on the board
/ESP_RXD: U12.98 (UART_ESP_TX); also elsewhere on the board
/ESP_STATUS: U12.95 (ESP_STATUS); also elsewhere on the board
/ESP_TXD: U12.97 (UART_ESP_RX); also elsewhere on the board
/PDU_CAN+: JP2.2 (B), U5.7 (CANH), U6.1; also elsewhere on the board
/PDU_CAN-: JP1.2 (B), U5.6 (CANL), U6.2; also elsewhere on the board
/PDU_FAULT: R19.2, U12.93 (PDU_FAULT); also elsewhere on the board
/STM32 MCU/BOOT0: R25.2, U12.94 (BOOT0)
/STM32 MCU/BUZZER_N: R26.1, U12.38 (BUZZER_N)
/STM32 MCU/BUZZER_P: R27.1, U12.39 (BUZZER_P)
/STM32 MCU/CAN_MTR_L_RX: U12.59 (CAN_MTR_L_RX), U16.4 (RXD)
/STM32 MCU/CAN_MTR_L_STB: U12.61 (CAN_MTR_L_STB), U16.8 (STB)
/STM32 MCU/CAN_MTR_L_TX: U12.60 (CAN_MTR_L_TX), U16.1 (TXD)
/STM32 MCU/CAN_MTR_R_RX: U12.70 (CAN_MTR_R_RX), U15.4 (RXD)
/STM32 MCU/CAN_MTR_R_STB: U12.69 (CAN_MTR_R_STB), U15.8 (STB)
/STM32 MCU/CAN_MTR_R_TX: U12.71 (CAN_MTR_R_TX), U15.1 (TXD)
/STM32 MCU/CAN_PDU_RX: U5.4 (RXD), U12.91 (CAN_PDU_RX)
/STM32 MCU/CAN_PDU_STB: U5.8 (STB), U12.90 (CAN_PDU_STB)
/STM32 MCU/CAN_PDU_TX: U5.1 (TXD), U12.92 (CAN_PDU_TX)
/STM32 MCU/DBG_UART_RX: J5.7, U12.87 (UART_DBG_RX)
/STM32 MCU/DBG_UART_TX: J5.8, U12.86 (UART_DBG_TX)
/STM32 MCU/ETH_CRS_DV: U12.31 (ETH_CRS_DV); also elsewhere on the board
/STM32 MCU/ETH_MDC: U12.16 (ETH_MDC); also elsewhere on the board
/STM32 MCU/ETH_MDIO: U12.24 (ETH_MDIO); also elsewhere on the board
/STM32 MCU/ETH_NRST: U12.46 (ETH_NRST); also elsewhere on the board
/STM32 MCU/ETH_REF_CLK: U12.23 (ETH_REF_CLK); also elsewhere on the board
/STM32 MCU/ETH_RXD0: U12.32 (ETH_RXD0); also elsewhere on the board
/STM32 MCU/ETH_RXD1: U12.33 (ETH_RXD1); also elsewhere on the board
/STM32 MCU/ETH_TXD0: U12.51 (ETH_TXD0); also elsewhere on the board
/STM32 MCU/ETH_TXD1: U12.52 (ETH_TXD1); also elsewhere on the board
/STM32 MCU/ETH_TXEN: U12.47 (ETH_TX_EN); also elsewhere on the board
/STM32 MCU/EXP_GPIO0: J4.15, U12.83 (EXP_GPIO0)
/STM32 MCU/EXP_GPIO1: J4.16, U12.84 (EXP_GPIO1)
/STM32 MCU/EXP_GPIO2: J4.13, U12.85 (EXP_GPIO2)
/STM32 MCU/EXP_GPIO3: J4.14, U12.88 (EXP_GPIO3)
/STM32 MCU/EXP_I2C_SCL: J4.11, R33.2, U12.67 (EXP_I2C_SCL)
/STM32 MCU/EXP_I2C_SDA: J4.12, R32.2, U12.66 (EXP_I2C_SDA)
/STM32 MCU/EXP_UART_RX: J4.9, U12.81 (EXP_UART_RX)
/STM32 MCU/EXP_UART_TX: J4.10, U12.82 (EXP_UART_TX)
/STM32 MCU/IMU0_INT1: U7.4 (INT1), U12.2 (IMU0_INT1)
/STM32 MCU/IMU0_INT2: U7.9 (INT2), U12.3 (IMU0_INT2)
/STM32 MCU/IMU0_MISO: U7.1 (SDO/SA0), U12.4 (IMU0_MISO)
/STM32 MCU/IMU0_MOSI: U7.14 (SDA), U12.5 (IMU0_MOSI)
/STM32 MCU/IMU0_SCK: U7.13 (SCL), U12.1 (IMU0_SCK)
/STM32 MCU/IMU0_~CS: U7.12 (~CS), U12.7 (IMU0_NCS)
/STM32 MCU/IMU1_INT1: J7.8, U12.68 (IMU1_INT1)
/STM32 MCU/IMU1_MISO: R53.2, U12.79 (IMU1_MISO)
/STM32 MCU/IMU1_MOSI: R51.2, U12.80 (IMU1_MOSI)
/STM32 MCU/IMU1_SCK: R52.2, U12.78 (IMU1_SCK)
/STM32 MCU/IMU1_~CS: R54.2, U12.77 (IMU1_NCS)
/STM32 MCU/LED_0: R20.2, U12.15 (LED_0)
/STM32 MCU/LED_1: R24.2, U12.17 (LED_1)
/STM32 MCU/MCU_HB: U10.4 (WDI), U12.18 (MCU_HB)
/STM32 MCU/MTR_L_CAN+: J9.2, JP5.2 (B), U16.7 (CANH), U18.1
/STM32 MCU/MTR_L_CAN-: J9.1, JP6.2 (B), U16.6 (CANL), U18.2
/STM32 MCU/MTR_R_CAN+: J8.2, JP4.2 (B), U15.7 (CANH), U17.1
/STM32 MCU/MTR_R_CAN-: J8.1, JP3.2 (B), U15.6 (CANL), U17.2
/STM32 MCU/OSC32_IN: C16.2, U12.8 (RCC_OSC32_IN), Y1.1
/STM32 MCU/OSC32_OUT: R22.1, U12.9 (RCC_OSC32_OUT)
/STM32 MCU/OSC_IN: R23.1, U12.12 (RCC_OSC_IN)
/STM32 MCU/SWCLK: J5.4, U12.76 (DBG_SWCLK)
/STM32 MCU/SWDIO: J5.2, U12.72 (DBG_SWDIO)
/STM32 MCU/SWO: J5.6, U12.89 (DBG_SWO)
/STM32 MCU/THERM: R21.1, TH1.1, U12.22 (THERMISTOR)
/STM32 MCU/VBAT: J3.2, R16.1, U12.6 (VBAT)
/STM32 MCU/VCAP_1: C26.1, U12.48 (VCAP_1)
/STM32 MCU/VCAP_2: C30.1, U12.73 (VCAP_2)
/STM32 MCU/~MRST: SW2.2 (B), U10.3 (~MR)
/STM32 MCU/~RST: J5.10, U10.1 (~RST), U12.14 (NRST)
GND: C5.1, C8.1, C9.2, C14.2, C15.2, C16.1, C17.1, C18.2, C20.1, C21.1, C22.2, C23.2, C24.1, C25.1, C26.2, C27.1, C28.1, C30.2, C38.1, C39.1, C41.1, C42.1, D3.1 (K), D4.1 (K), J3.1, J4.1, J4.2, J4.7, J4.8, J5.3, J5.5, J7.1, J7.2, R19.1, R25.1, SW2.1 (A), TH1.2, U5.2 (GND), U5.9 (EP), U6.3, U7.2 (SDx), U7.3 (SCx), U7.6 (GND), U7.7 (GND), U9.2 (GND), U10.2 (VSS), U12.10 (VSS_1), U12.19 (VSSA), U12.26 (VSS_2), U12.49 (VSS_3), U12.74 (VSS_4), U12.99 (VSS_5), U15.2 (GND), U15.9 (EP), U16.2 (GND), U16.9 (EP), U17.3, U18.3; also elsewhere on the board
unnamed: BZ1.1 (+), R27.2
unnamed: BZ1.2 (-), R26.2
unnamed: C8.2, R10.1, R15.2
unnamed: C17.2, R22.2, Y1.2
unnamed: C39.2, R45.2, R48.1
unnamed: C42.2, R49.2, R50.1
unnamed: D3.2 (A), R20.1
unnamed: D4.2 (A), R24.1
unnamed: F2.2, J4.3
unnamed: F1.1, J4.4
unnamed: J7.4, R54.1
unnamed: J7.5, R51.1
unnamed: J7.6, R52.1
unnamed: J7.7, R53.1
unnamed: JP1.1 (A), R10.2
unnamed: JP2.1 (A), R15.1
unnamed: JP3.1 (A), R48.2
unnamed: JP4.1 (A), R45.1
unnamed: JP5.1 (A), R49.1
unnamed: JP6.1 (A), R50.2
unnamed: R23.2, U9.3 (CLK)

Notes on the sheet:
STLINK
R16 and J7 are mutually exclusive. Never populate both
ETHERNET
MISC
SUPERVISOR
STM32H723VGT6
CAN TRANSCEIVERS
EXPANSION HEADER
IMUs
CLOCKS
VBAT

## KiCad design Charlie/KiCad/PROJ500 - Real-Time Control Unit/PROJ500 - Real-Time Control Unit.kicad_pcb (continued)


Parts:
C29, C34, C35: 100nF/50V(10%); C_0402_1005Metric
C31, C33: 1uF/16V(10%); C_0603_1608Metric
C32: 470pF/50V(10%); C_0402_1005Metric
C36: 22nF/50V(10%); C_0402_1005Metric
C37: 4.7uF/16V(10%); C_0805_2012Metric
C40: 1nF/2kV(10%); C_1206_3216Metric
FB2: 220R/0.6A; L_0402_1005Metric
J6: RJ45_Amphenol_RJMG1BD3B8K1ANR
R28, R29, R30: 10R(10%); R_0402_1005Metric
R31: 1.5k(10%); R_0402_1005Metric
R34: 33R(10%); R_0402_1005Metric
R35: 0R(10%); R_0402_1005Metric
R36, R43: 510k/500V(10%); R_1206_3216Metric
R37: 12.1k(1%); R_0402_1005Metric
R38, R42: 330R(10%); R_0402_1005Metric
R39, R44: 4.7k(10%); R_0402_1005Metric
R40, R41, R46, R47: 49.9R(1%); R_0402_1005Metric
U13: CDC6CEx; Oscillator_SMD_VSON-4_2x1.6mm
U14: LAN8742A; VQFN-24-1EP_4x4mm_P0.5mm_EP2.5x2.5mm

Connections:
+3.3V: C29.1, C33.1, FB2.1, R31.2, U13.4 (VDD), U14.9 (VDDIO); also elsewhere on the board
/STM32 MCU/ETHERNET/ETH_SHIELD: C40.1, J6.R8, J6.SH, R43.1
/STM32 MCU/ETHERNET/ETH_SH_R: R36.1, R43.2
/STM32 MCU/ETHERNET/LED1: R42.1, U14.3 (LED1/REGOFF)
/STM32 MCU/ETHERNET/LED2: R38.1, U14.2 (LED2/~INTSEL)
/STM32 MCU/ETHERNET/RXN: J6.R6 (RD-), R46.1, U14.22 (RXN)
/STM32 MCU/ETHERNET/RXP: J6.R3 (RD+), R40.1, U14.23 (RXP)
/STM32 MCU/ETHERNET/TXN: J6.R2 (TD-), R41.1, U14.20 (TXN)
/STM32 MCU/ETHERNET/TXP: J6.R1 (TD+), R47.1, U14.21 (TXP)
/STM32 MCU/ETHERNET/VDDA: C34.1, C35.1, C36.1, C37.1, FB2.2, J6.R4 (TCT), J6.R5 (RCT), R40.2, R41.2, R46.2, R47.2, U14.1 (VDD2A), U14.19 (VDD1A)
/STM32 MCU/ETH_CRS_DV: R30.2; also elsewhere on the board
/STM32 MCU/ETH_MDC: U14.13 (MDC); also elsewhere on the board
/STM32 MCU/ETH_MDIO: R31.1, U14.12 (MDIO); also elsewhere on the board
/STM32 MCU/ETH_NRST: U14.15 (~RST); also elsewhere on the board
/STM32 MCU/ETH_REF_CLK: R34.2; also elsewhere on the board
/STM32 MCU/ETH_RXD0: R29.2; also elsewhere on the board
/STM32 MCU/ETH_RXD1: R28.2; also elsewhere on the board
/STM32 MCU/ETH_TXD0: U14.17 (TXD0); also elsewhere on the board
/STM32 MCU/ETH_TXD1: U14.18 (TXD1); also elsewhere on the board
/STM32 MCU/ETH_TXEN: U14.16 (TXEN); also elsewhere on the board
GND: C29.2, C31.1, C32.1, C33.2, C34.2, C35.2, C36.2, C37.2, C40.2, J6.L2, J6.L3, R36.2, R37.1, R39.2, R44.1, U13.2 (GND), U14.25 (VSS); also elsewhere on the board
unnamed: J6.L1, R38.2, R39.1
unnamed: J6.L4, R42.2, R44.2
unnamed: R35.2, U13.3 (CLK)
unnamed: R30.1, U14.11 (CRS_DV/MODE2)
unnamed: R37.2, U14.24 (RBIAS)
unnamed: R29.1, U14.8 (RXD0/MODE0)
unnamed: R28.1, U14.7 (RXD1/MODE1)
unnamed: C31.2, C32.2, U14.6 (VDDCR)
unnamed: R35.1, U14.5 (XTAL1/CLKIN)
unnamed: R34.1, U14.14 (~INT/REFCLKO)


Board: 2 copper layers, 79.6 x 61.4 mm, 155 parts (0 on the bottom side), 134 nets.

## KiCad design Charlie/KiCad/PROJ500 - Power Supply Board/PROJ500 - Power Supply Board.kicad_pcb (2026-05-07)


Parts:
C4: 100uF/100V(20%); CP_Radial_D10.0mm_P5.00mm
C5: 10uF/50V(10%); C_1206_3216Metric
C7, C9, C33, C66, C82, C83, C111: 100nF/50V(10%); C_0402_1005Metric
C10, C25: 100nF/100V(20%); C_0603_1608Metric
C11, C24: 2.2uF/100V(10%); C_0805_2012Metric
C12, C13, C14: 10uF/100V(10%); C_1210_3225Metric
C41: 1uF/100V(10%); C_0603_1608Metric
C70: 2.2uF/25V(10%); C_0805_2012Metric
C72, C78: 4.7uF/16V(10%); C_0805_2012Metric
C79: 1uF/25V(10%); C_0603_1608Metric
D2: VSSB410S; D_SMB
D4: OR_FAN; D_0805_2012Metric
D5, D7: SMC5K60A; D_SMC
D6: OR_VRAW_PRESENT; D_0805_2012Metric
D9: SMBJ26A; D_SMB
D10: SMCJ15A; D_SMC
D11: SMBJ6.0A; D_SMB
D12: GR_12V_PGOOD; D_0805_2012Metric
D13: GR_24V_SW_PGOOD; D_0805_2012Metric
D14: GR_12V_SW_PGOOD; D_0805_2012Metric
D15: GR_SW_PGOOD; D_0805_2012Metric
D16: RED_SW_FAULT; D_0805_2012Metric
F1: 3x20mm/8A; 65600301009
F2, F5: MINI297/10A; Fuseholder_Blade_Mini_Keystone_3568
F3: 2016L260/24MR; FUSC5141X160N
F4, F6: 2016L300/16MR; FUSC5141X160N
H1, H2, H3, H4, H5, H6: MountingHole; MountingHole_3.2mm_M3
J1: VRAW; AMASS_XT30PW-M_1x02_P2.50mm_Horizontal
J2: 12V_FAN; Molex_Micro-Fit_3.0_43045-0200_2x01_P3.00mm_Horizontal
J3: VRAW_SW; AMASS_XT30PW-F_1x02_P2.50mm_Horizontal
J4: 24V_SW; TBP02R138102BE
J5: EN; Molex_Micro-Fit_3.0_43045-0200_2x01_P3.00mm_Horizontal
J6: 24V_SW; Molex_Micro-Fit_3.0_43045-0400_2x02_P3.00mm_Horizontal
J7: 12V_SW; Molex_Micro-Fit_3.0_43045-0200_2x01_P3.00mm_Horizontal
J8: B2B_PWR; Molex_Micro-Fit_3.0_43045-0800_2x04_P3.00mm_Horizontal
J9, J10: 12V_SW; TBP02R138102BE
J11: B2B_SIG; Molex_Micro-Fit_3.0_43045-0800_2x04_P3.00mm_Horizontal
J12: 5V_SW; TBP02R138102BE
NT1: NetTie_2; NetTie-2_SMD_Pad0.5mm
Q3: SIA469DJ; SIA469DJT1GE3
R11, R12, R13, R15, R19, R51, R84, R87, R88: 10k(10%); R_0402_1005Metric
R17, R18: 27k(10%); R_0402_1005Metric
R20: 100R(10%); R_0402_1005Metric
R39, R42: 51k(10%); R_0402_1005Metric
R45, R48: 5m/2W(1%); R_2512_6332Metric
R54, R59: 330k(10%); R_0402_1005Metric
R55: 0R(10%); R_0402_1005Metric; not fitted
R56, R89, R90, R91, R92, R93: 1k(10%); R_0402_1005Metric
R57: 13k(1%); R_0402_1005Metric
R58, R60, R61: 10k(1%); R_0402_1005Metric
TH1, TH2: NTC/10K; R_0402_1005Metric
TP1: I_VRAW_SW; TestPoint_Pad_D1.0mm
TP2: VRAW; TestPoint_Pad_D1.0mm
TP3: VRAW_SW; TestPoint_Pad_D1.0mm
TP4: 12V; TestPoint_Pad_D1.0mm
TP5: 24V_SW; TestPoint_Pad_D1.0mm
TP6, TP11: 5V_SW; TestPoint_Pad_D1.0mm
TP7: 12V_SW; TestPoint_Pad_D1.0mm
TP8: 3.3V; TestPoint_Pad_D1.0mm
TP9: SDA; TestPoint_Pad_D1.0mm
TP10: SCL; TestPoint_Pad_D1.0mm
U2: 74LVC2G14GW; SOT-363_SC-70-6
U7: AP2114HA-3.3TRG1; SOT-223; Mouser Part Number 621-AP2114HA-3.3TRG1
U9: 2.5V; SOT-23-3; Part Number LM4040B25FTA
U11: LM393; TSSOP-8_4.4x3mm_P0.65mm
U14: 74LVC3G17GT,115; XC7WT14GT115

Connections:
5V_SW: F6.1, TP11.1; also elsewhere on the board
12V_SW: F5.1, R48.2, TP7.1; also elsewhere on the board
24V_SW: F2.1, R45.2, TP5.1; also elsewhere on the board
+3.3V: C9.1, C78.2, C79.1, C82.1, C111.2, R11.2, R19.2, R56.1, R60.2, R61.2, R84.2, R87.2, R88.2, TP8.1, U2.5 (V_{CC}), U7.3 (VOUT), U11.8 (V+), U14.8 (VCC); also elsewhere on the board
+5V: C72.2, F4.1, TP6.1, U7.1 (VIN); also elsewhere on the board
+12V: F3.1, Q3.S, R51.2, TP4.1; also elsewhere on the board
/5V_OUT_P: F4.2, J8.5
/5V_SW_OUT_P: D11.1 (K), F6.2, J8.6, J12.2
/12V_OUT_P: F3.2, J8.7
/12V_PGOOD: R84.1, U14.1; also elsewhere on the board
/12V_SW_OUT_P: C66.2, C70.2, D10.1 (K), F5.2, J7.1, J8.4, J8.8, J9.1, J10.1
/12V_SW_PGOOD: R87.1, U14.6; also elsewhere on the board
/24V_SW_OUT_P: C33.2, C41.1, D9.1 (K), F2.2, J4.2, J6.3, J6.4
/24V_SW_PGOOD: J11.5, R88.1, U14.3; also elsewhere on the board
/AON_EN: J5.2; also elsewhere on the board
/I_12V_SW_P: R48.1; also elsewhere on the board
/I_24V_SW_P: R45.1; also elsewhere on the board
/SCL: J11.8, TP10.1; also elsewhere on the board
/SDA: J11.4, TP9.1; also elsewhere on the board
/SW_EN: J11.3; also elsewhere on the board
/SW_FAULT: J11.7, R15.2, R90.2, U2.6 (1Y)
/SW_IMON: TP1.1; also elsewhere on the board
/SW_PGOOD: J11.6, R12.1, R89.2, U2.4 (2Y); also elsewhere on the board
/THERM_0: R54.1, R60.1, TH1.1, U11.3 (+); also elsewhere on the board
/THERM_1: R59.1, R61.1, TH2.1, U11.5 (+); also elsewhere on the board
/T_REF: R57.2, R58.2, U11.2 (-), U11.6 (-)
/VRAW_IN_P: F1.1, J1.2
/~SW_FAULT: R19.1, U2.1 (1A); also elsewhere on the board
/~SW_PGOOD: R11.1, U2.3 (2A); also elsewhere on the board
GNDA: C72.1, C78.1, C79.2, C82.2, C83.2, C111.1, D12.1 (K), D13.1 (K), D14.1 (K), D15.1 (K), D16.1 (K), J11.1, J11.2, NT1.2, R55.2, R58.1, TH1.2, TH2.2, U7.2 (GND_1), U7.4 (GND_2), U9.2 (A), U11.4 (V-), U14.4 (GND); also elsewhere on the board
GNDPWR: C4.2, C5.2, C7.2, C9.2, C10.1, C11.2, C12.2, C13.2, C14.2, C24.2, C25.1, C33.1, C41.2, C66.1, C70.1, D2.2 (A), D4.1 (K), D5.2 (A), D6.1 (K), D7.2 (A), D9.2 (A), D10.2 (A), D11.2 (A), J1.1, J2.1, J3.1, J4.1, J6.1, J6.2, J7.2, J8.1, J8.2, J8.3, J9.2, J10.2, J12.1, NT1.1, R12.2, R15.1, R42.2, U2.2 (GND); also elsewhere on the board
unnamed: C5.1, C7.1, D2.1 (K), J2.2, Q3.D, R13.2
unnamed: D4.2 (A), R13.1
unnamed: D6.2 (A), R17.1
unnamed: D12.2 (A), R93.2
unnamed: D13.2 (A), R91.2
unnamed: D14.2 (A), R92.2
unnamed: D15.2 (A), R89.1
unnamed: D16.2 (A), R90.1
unnamed: J5.1, R39.1, R42.1
unnamed: Q3.G, R20.2
unnamed: R17.2, R18.1
unnamed: R20.1, R51.1, R54.2, R55.1, R59.2, U11.1, U11.7
unnamed: R91.1, U14.5
unnamed: R92.1, U14.2
unnamed: R93.1, U14.7
unnamed: C83.1, R56.2, R57.1, U9.1 (K)
VRAW: C4.1, C10.2, C11.1, C12.1, C13.1, C14.1, D7.1 (K), F1.2, R18.2, R39.2, TP2.1; also elsewhere on the board
VRAW_SW: C24.1, C25.2, D5.1 (K), J3.2, TP3.1; also elsewhere on the board

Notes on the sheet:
ADC
CIRCUIT PROTECTION
*Increase F1 rating from 8A as external load is added to VRAW_SW*
SWITCH
LEDS
CURRENT/TEMP SENSE
CONNECTORS
PSU
MOUNTING


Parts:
C69, C90: 100uF/35\V(20%); CAPAE830X700N
C73, C74, C75, C76, C86, C87, C88, C89: 10uF/50V(10%); C_1206_3216Metric
C77, C107: 100nF/50V(10%); C_0402_1005Metric
C85: 1uF/16V(10%); C_0603_1608Metric
C96: 4.7uF/16V(10%); C_0805_2012Metric
C99: 1uF/100V(10%); C_0603_1608Metric
C100: 100nF/100V(20%); C_0603_1608Metric
L5: 6.8uH/11.5A(20%); INDPM135125X650N
NT2: NetTie_2; NetTie-2_SMD_Pad0.5mm
R65: 4.3k(1%); R_0402_1005Metric
R67: 82k(1%); R_0402_1005Metric
R72: 2.2R(10%); R_0402_1005Metric
R73, R74: 100k(1%); R_0402_1005Metric
U10: SIC437A; Vishay_PowerPAK_MLP44-24L

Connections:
24V_SW: C86.1, C87.1, C88.1, C89.1, C90.1, C99.1, C100.1, U10.1 (V_{IN}), U10.2 (V_{IN}), U10.19 (EN), U10.22 (V_{IN}), U10.26 (V_{IN}); also elsewhere on the board
/12V_SW_PGOOD: U10.14 (P_{GOOD}); also elsewhere on the board
/I_12V_SW_P: C69.1, C73.1, C74.1, C75.1, C76.1, C77.1, L5.2, R67.2, U10.18 (V_{OUT}); also elsewhere on the board
/SiC437 - 12V 8A/AGND: C85.1, NT2.1, R65.1, U10.16 (A_{GND}), U10.25 (A_{GND})
/SiC437 - 12V 8A/VDD: C85.2, R73.1, R74.1, U10.15 (V_{DD})
GNDPWR: C69.2, C73.2, C74.2, C75.2, C76.2, C77.2, C86.2, C87.2, C88.2, C89.2, C90.2, C96.2, C99.2, C100.2, NT2.2, U10.3 (P_{GND}), U10.4 (P_{GND}), U10.13 (P_{GND}), U10.27 (P_{GND}); also elsewhere on the board
unnamed: C107.2, R72.2
unnamed: L5.1, U10.5 (SW), U10.6 (SW), U10.7 (SW), U10.8 (SW), U10.9 (SW)
unnamed: R72.1, U10.23 (BOOT)
unnamed: R65.2, R67.1, U10.17 (FB)
unnamed: R73.2, U10.21 (MODE1)
unnamed: R74.2, U10.20 (MODE2)
unnamed: C107.1, U10.24 (PHASE)
unnamed: C96.1, U10.12 (V_{DRV})


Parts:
C61: 100pF/50V(10%); C_0402_1005Metric
C62: 10uF/50V(10%); C_1206_3216Metric
C63, C65: 100nF/50V(10%); C_0402_1005Metric
C64: 470nF/25V(10%); C_0603_1608Metric
C67, C68: 22uF/10V(10%); C_0805_2012Metric
L4: 4.7uH/3A(20%); ASPI-4030S
R46: 10k(1%); R_0402_1005Metric
R47: 52.3k(1%); R_0402_1005Metric
U6: AP62200Z6-7; SOT-563; Mouser Part Number 621-AP62200Z6-7

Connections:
+5V: C61.2, C65.1, C67.1, C68.1, L4.1, R47.1; also elsewhere on the board
+12V: C62.1, C63.1, U6.1 (VIN); also elsewhere on the board
GNDPWR: C62.2, C63.2, C65.2, C67.2, C68.2, R46.2, U6.3 (GND); also elsewhere on the board
unnamed: C64.1, U6.4 (BST)
unnamed: C61.1, R46.1, R47.2, U6.6 (FB)
unnamed: C64.2, L4.2, U6.2 (SW)

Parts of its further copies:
C84, C93: 22uF/10V(10%); C_0805_2012Metric
C91: 10uF/50V(10%); C_1206_3216Metric
C98, C102: 100nF/50V(10%); C_0402_1005Metric
C109: 100pF/50V(10%); C_0402_1005Metric
C110: 470nF/25V(10%); C_0603_1608Metric
L6: 4.7uH/3A(20%); ASPI-4030S
R70: 10k(1%); R_0402_1005Metric
R80: 52.3k(1%); R_0402_1005Metric
U13: AP62200Z6-7; SOT-563; Mouser Part Number 621-AP62200Z6-7

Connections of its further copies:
5V_SW: C84.1, C93.1, C98.1, C109.2, L6.1, R80.1; also elsewhere on the board
12V_SW: C91.1, C102.1, U13.1 (VIN); also elsewhere on the board
GNDPWR: C84.2, C91.2, C93.2, C98.2, C102.2, R70.2, U13.3 (GND); also elsewhere on the board
unnamed: C110.1, U13.4 (BST)
unnamed: C109.1, R70.1, R80.2, U13.6 (FB)
unnamed: C110.2, L6.2, U13.2 (SW)


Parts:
C3: 100uF/100V(20%); CP_Radial_D10.0mm_P5.00mm
C15: 10uF/100V(10%); C_1210_3225Metric
C17, C18, C19: 2.2uF/100V(10%); C_0805_2012Metric
C20, C21: 100nF/100V(20%); C_0603_1608Metric
C22, C30: 100nF/50V(10%); C_0402_1005Metric
C23: 1uF/100V(10%); C_0603_1608Metric
C26, C28: 2.2uF/25V(10%); C_0805_2012Metric
C29: C_0603_1608Metric; not fitted
C31: 4.7uF/16V(10%); C_0805_2012Metric
C35, C39: 10uF/50V(10%); C_1206_3216Metric
C37: 4.7nF/50V(10%); C_0402_1005Metric
C42, C44: 10uF/50V(10%); C_1206_3216Metric; not fitted
C59: 100uF/35\V(20%); CAPAE830X700N
L1: 1uH/5A(20%); L_1008_2520Metric
L2: 28uH/9A(15%); PA2729283NL
NT3: NetTie_2; NetTie-2_SMD_Pad0.5mm
R22: 2.2R/0.125W(10%); R_0805_2012Metric
R23: 100k/0.125W(1%); R_0603_1608Metric
R24: 53.6k/0.125W(1%); R_0805_2012Metric
R25: 1.3k(1%); R_0402_1005Metric
R26: 62k(1%); R_0402_1005Metric
R27: 2.2R/0.125W(10%); R_0603_1608Metric
R28: R_0805_2012Metric; not fitted
R29: 205R(1%); R_0402_1005Metric
R33: 3.9k/0.125W(1%); R_0603_1608Metric
R41: 10k(10%); R_0402_1005Metric
U3: MIC28517T-E/PHA; VQFN32_6X6_3EP_PHA_MCH

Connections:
+12V: C28.2, C30.1, C35.1, C37.2, C39.1, C42.1, C44.1, C59.1, L2.1, R33.2, U3.23 (EXTVDD); also elsewhere on the board
/12V_PGOOD: U3.32 (PG); also elsewhere on the board
/AON_EN: R41.1, U3.24 (EN); also elsewhere on the board
/MIC28517 - 12V 4A/AGND: C23.2, NT3.2, R26.2, R29.1, U3.26 (MODE), U3.28 (AGND)
/MIC28517 - 12V 4A/FB: C22.2, C37.1, R29.2, R33.1, U3.27 (FB)
/MIC28517 - 12V 4A/FREQ: R23.1, R26.1, U3.25 (FREQ)
/MIC28517 - 12V 4A/ILIM: R25.1, U3.1 (ILIM)
/MIC28517 - 12V 4A/SVIN: C23.1, R22.2, U3.31 (SVIN)
/MIC28517 - 12V 4A/SW: C20.1, L2.2, R24.2, R25.2, R28.2, U3.3 (SW), U3.12 (SW), U3.13 (SW), U3.14 (SW), U3.15 (SW), U3.20 (SW), U3.EP12 (SW)
/MIC28517 - 12V 4A/VDD: C26.2, R27.1, U3.30 (VDD)
/MIC28517 - 12V 4A/VIN_F: C3.1, C15.1, C17.1, C18.1, C19.1, C21.1, L1.2, R22.1, R23.2, U3.5 (PVIN), U3.6 (PVIN), U3.7 (PVIN), U3.8 (PVIN), U3.9 (PVIN), U3.10 (PVIN), U3.11 (PVIN), U3.EP5 (PVIN)
GNDPWR: C3.2, C15.2, C17.2, C18.2, C19.2, C21.2, C26.1, C28.1, C29.2, C30.2, C31.1, C35.2, C39.2, C42.2, C44.2, C59.2, NT3.1, R41.2, U3.2 (PGND), U3.16 (PGND), U3.17 (PGND), U3.18 (PGND), U3.19 (PGND), U3.22 (PGND), U3.29 (PGND), U3.33 (PGND), U3.EP19 (PGND); also elsewhere on the board
unnamed: C22.1, R24.1
unnamed: C29.1, R28.1
unnamed: C20.2, U3.4 (BST)
unnamed: C31.2, R27.2, U3.21 (PVDD)
VRAW: L1.1; also elsewhere on the board


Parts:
C27: 100uF/100V(20%); CP_Radial_D10.0mm_P5.00mm
C32: 2.2uF/25V(10%); C_0805_2012Metric
C34: 1uF/100V(10%); C_0603_1608Metric
C36, C50: 100nF/50V(10%); C_0402_1005Metric
C38, C46: 100nF/100V(20%); C_0603_1608Metric
C40: 100uF/35\V(20%); CAPAE830X700N
C43: 4.7nF/50V(10%); C_0402_1005Metric
C45: 4.7uF/16V(10%); C_0805_2012Metric
C47, C48, C49: 2.2uF/100V(10%); C_0805_2012Metric
C51: C_0603_1608Metric; not fitted
C52: 10uF/100V(10%); C_1210_3225Metric
C53, C54: 10uF/50V(10%); C_1206_3216Metric; not fitted
C55, C56: 10uF/50V(10%); C_1206_3216Metric
FB1: 50R/12A; L_1206_3216Metric
L3: 22uH/18A(20%); PA2247.223NLT
NT4: NetTie_2; NetTie-2_SMD_Pad0.5mm
R30: 35.7k/0.125W(1%); R_0805_2012Metric
R31: 2.4k(1%); R_0402_1005Metric
R32: 62k(1%); R_0402_1005Metric
R34: 255R(1%); R_0402_1005Metric
R35: 2.2R/0.125W(10%); R_0603_1608Metric
R36: 2.2R/0.125W(10%); R_0805_2012Metric
R37: 100k/0.125W(1%); R_0603_1608Metric
R38: 10k/0.125W(1%); R_0603_1608Metric
R40: R_0805_2012Metric; not fitted
U4: MIC28517T-E/PHA; VQFN32_6X6_3EP_PHA_MCH

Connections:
/24V_SW_PGOOD: U4.32 (PG); also elsewhere on the board
/I_24V_SW_P: C40.1, C43.2, C50.1, C53.1, C54.1, C55.1, C56.1, L3.1, R38.2; also elsewhere on the board
/MIC28517 - 24V 8A/AGND: C34.2, NT4.2, R32.2, R34.1, U4.28 (AGND)
/MIC28517 - 24V 8A/FB: C36.2, C43.1, R34.2, R38.1, U4.27 (FB)
/MIC28517 - 24V 8A/FREQ: R32.1, R37.1, U4.25 (FREQ)
/MIC28517 - 24V 8A/ILIM: R31.1, U4.1 (ILIM)
/MIC28517 - 24V 8A/SVIN: C34.1, R36.2, U4.31 (SVIN)
/MIC28517 - 24V 8A/SW: C38.1, L3.2, R30.2, R31.2, R40.2, U4.3 (SW), U4.12 (SW), U4.13 (SW), U4.14 (SW), U4.15 (SW), U4.20 (SW), U4.EP12 (SW)
/MIC28517 - 24V 8A/VDD: C32.2, R35.1, U4.26 (MODE), U4.30 (VDD)
/MIC28517 - 24V 8A/VIN_F: C27.1, C46.1, C47.1, C48.1, C49.1, C52.1, FB1.2, R36.1, R37.2, U4.5 (PVIN), U4.6 (PVIN), U4.7 (PVIN), U4.8 (PVIN), U4.9 (PVIN), U4.10 (PVIN), U4.11 (PVIN), U4.EP5 (PVIN)
/SW_PGOOD: U4.24 (EN); also elsewhere on the board
GNDPWR: C27.2, C32.1, C40.2, C45.1, C46.2, C47.2, C48.2, C49.2, C50.2, C51.2, C52.2, C53.2, C54.2, C55.2, C56.2, NT4.1, U4.2 (PGND), U4.16 (PGND), U4.17 (PGND), U4.18 (PGND), U4.19 (PGND), U4.22 (PGND), U4.23 (EXTVDD), U4.29 (PGND), U4.33 (PGND), U4.EP19 (PGND); also elsewhere on the board
unnamed: C36.1, R30.1
unnamed: C51.1, R40.1
unnamed: C38.2, U4.4 (BST)
unnamed: C45.2, R35.2, U4.21 (PVDD)
VRAW_SW: FB1.1; also elsewhere on the board


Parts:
C57, C81: 2.2uF/10V(10%); C_0603_1608Metric
C58, C80: 100nF/50V(10%); C_0402_1005Metric
C60, C71: 100pF/50V(10%); C_0402_1005Metric
R43, R44, R49, R50: 4.7R(1%); R_0402_1005Metric
U5, U8: MCP6C26T-050E_LTY; SOT-363_SC-70-6; Manufacturer_Part_Number MCP6C26T-050E/LTY

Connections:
12V_SW: R50.2; also elsewhere on the board
24V_SW: R43.2; also elsewhere on the board
+3.3V: C57.1, C58.1, C80.1, C81.1, U5.3 (VDD), U8.3 (VDD); also elsewhere on the board
/I_12V_SW: U8.6 (VOUT); also elsewhere on the board
/I_12V_SW_P: R49.2; also elsewhere on the board
/I_24V_SW: U5.6 (VOUT); also elsewhere on the board
/I_24V_SW_P: R44.2; also elsewhere on the board
GNDA: C57.2, C58.2, C80.2, C81.2, U5.1 (VREF), U5.2 (VSS), U8.1 (VREF), U8.2 (VSS); also elsewhere on the board
unnamed: C60.1, R43.1, U5.5 (VIM)
unnamed: C60.2, R44.1, U5.4 (VIP)
unnamed: C71.1, R50.1, U8.5 (VIM)
unnamed: C71.2, R49.1, U8.4 (VIP)

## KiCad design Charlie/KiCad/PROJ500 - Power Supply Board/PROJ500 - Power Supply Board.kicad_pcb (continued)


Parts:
C1: 100nF/50V(10%); C_0402_1005Metric
C2: 3.3nF/50V(10%); C_0402_1005Metric
C6: 2.2uF/100V(10%); C_0805_2012Metric
C8, C16: 100nF/100V(20%); C_0603_1608Metric
D1: SMC5K60A; D_SMC
D3: Vz 10V; D_SOD-323
D8: SS1150-LTP; D_SMA
Q1: MMBT3904; SOT-23
Q2: 2N7002K; SOT-23
Q4: IPB042N10N3G; TO-263-3_TabPin2
R1, R2: 10k(1%); R_0402_1005Metric
R3: 51k(1%); R_0402_1005Metric
R4: 33k(1%); R_0402_1005Metric
R5, R7: 10k(10%); R_0402_1005Metric
R6: 100k(10%); R_0402_1005Metric
R8: 470k(1%); R_0805_2012Metric
R9: 1k(10%); R_0402_1005Metric
R10: 100k(10%); R_0805_2012Metric
R14: 1k(1%); R_0805_2012Metric
R16: 3m/2W(1%); R_2512_6332Metric
R21: 10R(1%); R_0603_1608Metric
U1: TPS2492PW; TSSOP-14_4.4x5mm_P0.65mm; Mouser Part Number 595-TPS2492PW

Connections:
/Hot Swap Switch/UVEN: Q2.3 (D), R4.1, R8.2, U1.1 (UVEN)
/SW_EN: R5.2; also elsewhere on the board
/SW_IMON: C1.1, R7.2; also elsewhere on the board
/~SW_FAULT: U1.9 (~FLT); also elsewhere on the board
/~SW_PGOOD: U1.8 (~PG); also elsewhere on the board
GNDPWR: C1.2, C2.2, C6.2, C8.1, C16.1, D1.2 (A), D3.2 (A), D8.2 (A), Q1.2 (E), Q2.2 (S), R1.2, R2.2, R6.1, U1.7 (GND); also elsewhere on the board
unnamed: C16.2, R14.1
unnamed: D3.1 (K), Q1.3 (C), R9.1, R10.1
unnamed: Q1.1 (B), R5.1, R6.2
unnamed: Q2.1 (G), R9.2
unnamed: Q4.2 (D), R16.2, U1.13 (SENSE)
unnamed: Q4.1 (G), R21.1
unnamed: R14.2, R21.2, U1.12 (GATE)
unnamed: R7.1, U1.6 (IMON)
unnamed: R2.1, R4.2, U1.5 (OV)
unnamed: R1.1, R3.1, U1.3 (PROG)
unnamed: C2.1, U1.4 (TIMER)
unnamed: R3.2, U1.2 (VREF)
VRAW: C6.1, C8.2, D1.1 (K), R8.1, R10.2, R16.1, U1.14 (VCC); also elsewhere on the board
VRAW_SW: D8.1 (K), Q4.3 (S), U1.11 (OUT); also elsewhere on the board

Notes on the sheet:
ENABLE INPUT
UVLO = 14.9V OVLO = 69.3V Current Limit = 16.7A Theoretical Max Steady-State Temperature (RJA=20C/W) = 84C
MOSFET - IPB042N10N3GATMA1


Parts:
C92, C104, C105: 1uF/16V(10%); C_0603_1608Metric
C94, C95, C97, C106, C108, C112: 100nF/50V(10%); C_0402_1005Metric
C101, C103: 10nF/50V(10%); C_0402_1005Metric
FB2: 120R/3A; L_0603_1608Metric
R52, R53: 4.7k(10%); R_0402_1005Metric; not fitted
R62, R63, R68, R75, R83: 1K(1%); R_0402_1005Metric
R64, R66, R81: 100R(1%); R_0402_1005Metric
R69: 130K(1%); R_0402_1005Metric
R71, R78, R82: 10K(1%); R_0402_1005Metric
R76: 68K(1%); R_0402_1005Metric
R77, R79: 22R(10%); R_0402_1005Metric
R85, R86: 150K(1%); R_0402_1005Metric
U12: TLA2528IRTER; WQFN-16-1EP_3x3mm_P0.5mm_EP1.75x1.75mm; Mouser Part Number 595-TLA2528IRTER

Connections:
12V_SW: R76.2; also elsewhere on the board
24V_SW: R69.2; also elsewhere on the board
+3.3V: C105.2, FB2.2, R52.1, R53.2, U12.10 (DVDD); also elsewhere on the board
/I_12V_SW: R66.1; also elsewhere on the board
/I_24V_SW: R64.1; also elsewhere on the board
/SCL: R53.1, R77.2; also elsewhere on the board
/SDA: R52.2, R79.2; also elsewhere on the board
/SW_IMON: R81.2; also elsewhere on the board
/THERM_0: R63.1; also elsewhere on the board
/THERM_1: R62.1; also elsewhere on the board
/TLA2528 ADC/A0: C112.1, R83.2, U12.15 (AIN0/GPIO0)
/TLA2528 ADC/A1: R81.1, U12.16 (AIN1/GPIO1)
/TLA2528 ADC/A2: C108.1, R75.2, U12.1 (AIN2/GPIO2)
/TLA2528 ADC/A3: C106.1, R68.2, U12.2 (AIN3/GPIO3)
/TLA2528 ADC/A4: C103.2, R66.2, U12.3 (AIN4/GPIO4)
/TLA2528 ADC/A5: C101.2, R64.2, U12.4 (AIN5/GPIO5)
/TLA2528 ADC/A6: C97.2, R63.2, U12.5 (AIN6/GPIO6)
/TLA2528 ADC/A7: C94.2, R62.2, U12.6 (AIN7/GPIO7)
/TLA2528 ADC/DC: C104.1, U12.8 (DECAP), U12.11 (ADDR)
GNDA: C92.2, C94.1, C95.2, C97.1, C101.1, C103.1, C104.2, C105.1, C106.2, C108.2, C112.2, R71.1, R78.1, R82.1, U12.9 (GND), U12.17 (EP); also elsewhere on the board
unnamed: R68.1, R69.1, R71.2
unnamed: R75.1, R76.1, R78.2
unnamed: R82.2, R83.1, R85.1
unnamed: R85.2, R86.1
unnamed: C92.1, C95.1, FB2.1, U12.7 (AVDD)
unnamed: R77.1, U12.13 (SCL)
unnamed: R79.1, U12.14 (SDA)
VRAW: R86.2; also elsewhere on the board



Board: 2 copper layers, 130.0 x 115.0 mm, 288 parts (2 on the bottom side), 124 nets.

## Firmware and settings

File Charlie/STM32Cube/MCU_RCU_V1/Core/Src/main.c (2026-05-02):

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
/* Includes ------------------------------------------------------------------*/
#include "main.h"
#include "lwip.h"

/* USER CODE BEGIN Includes */
#if defined(RCU_BUILD_MODE_SELFTEST)
#include "rcu_selftest_cli_v1.h"
#elif defined(RCU_BUILD_MODE_RUNTIME)
#include "rcu_app.h"
#else
#error "Define RCU_BUILD_MODE_SELFTEST or RCU_BUILD_MODE_RUNTIME in IDE preprocessor settings"
#endif

/* USER CODE END Includes */

ADC_HandleTypeDef hadc1;

FDCAN_HandleTypeDef hfdcan1;
FDCAN_HandleTypeDef hfdcan2;
FDCAN_HandleTypeDef hfdcan3;

I2C_HandleTypeDef hi2c3;

RTC_HandleTypeDef hrtc;

SPI_HandleTypeDef hspi3;
SPI_HandleTypeDef hspi4;

TIM_HandleTypeDef htim1;

UART_HandleTypeDef huart4;
UART_HandleTypeDef huart8;
UART_HandleTypeDef huart2;

void SystemClock_Config(void);
static void MPU_Config(void);
static void MX_GPIO_Init(void);
static void MX_FDCAN1_Init(void);
static void MX_FDCAN2_Init(void);
static void MX_FDCAN3_Init(void);
static void MX_ADC1_Init(void);
static void MX_SPI4_Init(void);
static void MX_TIM1_Init(void);
static void MX_UART4_Init(void);
static void MX_UART8_Init(void);
static void MX_I2C3_Init(void);
static void MX_RTC_Init(void);
static void MX_SPI3_Init(void);
static void MX_USART2_UART_Init(void);
/* USER CODE BEGIN 0 */
extern void st_dbg_printf(const char *fmt, ...);
/* USER CODE END 0 */

/**
  * @brief  The application entry point.
  * @retval int
  */
int main(void)
{

  /* MPU Configuration--------------------------------------------------------*/
  MPU_Config();

  /* MCU Configuration--------------------------------------------------------*/

  /* Reset of all peripherals, Initializes the Flash interface and the Systick. */
  HAL_Init();

  /* Configure the system clock */
  SystemClock_Config();

  /* Initialize all configured peripherals */
  MX_GPIO_Init();
  MX_FDCAN1_Init();
  MX_FDCAN2_Init();
  MX_FDCAN3_Init();
  MX_ADC1_Init();
  MX_SPI4_Init();
  MX_TIM1_Init();
  MX_UART4_Init();
  MX_UART8_Init();
  MX_I2C3_Init();
  MX_RTC_Init();
  MX_SPI3_Init();
  MX_USART2_UART_Init();

  /* Boot diagnostic: print RSR BEFORE MX_LWIP_Init so we see the cause
   * even if LWIP init hangs or crashes before RCU_App_Init() runs.
   * PINRSTF = external NRST event (EMI? button?)
   * SFTRSTF = NVIC_SystemReset() from fault_indicate() or Error_Handler */
  {
    uint32_t rsr = RCC->RSR;
    st_dbg_printf("\r\n[BOOT] RSR=0x%08lX", (unsigned long)rsr);
    if (rsr & RCC_RSR_PINRSTF)   st_dbg_printf(" NRST");
    if (rsr & RCC_RSR_SFTRSTF)   st_dbg_printf(" SFTRST(fault/sw)");
    if (rsr & RCC_RSR_BORRSTF)   st_dbg_printf(" BOR");
    if (rsr & RCC_RSR_IWDG1RSTF) st_dbg_printf(" IWDG");
    if (rsr & RCC_RSR_WWDG1RSTF) st_dbg_printf(" WWDG");
    if (rsr & RCC_RSR_D1RSTF)    st_dbg_printf(" D1PWR");
    if (rsr & RCC_RSR_D2RSTF)    st_dbg_printf(" D2PWR");
    st_dbg_printf("\r\n");
    st_dbg_printf("[BOOT] MX_LWIP_Init starting...\r\n");
  }

  MX_LWIP_Init();
  /* USER CODE BEGIN 2 */
  st_dbg_printf("[BOOT] MX_LWIP_Init done.\r\n");
#if defined(RCU_BUILD_MODE_SELFTEST)
	RCU_SelfTest_Init();
#elif defined(RCU_BUILD_MODE_RUNTIME)
	RCU_App_Init();
#endif

  /* USER CODE END 2 */

  /* Infinite loop */
  /* USER CODE BEGIN WHILE */
	while (1) {
#if defined(RCU_BUILD_MODE_SELFTEST)
		RCU_SelfTest_Task();
#elif defined(RCU_BUILD_MODE_RUNTIME)
		RCU_App_Task();
#endif
    /* USER CODE END WHILE */

    /* USER CODE BEGIN 3 */
	}
  /* USER CODE END 3 */
}

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
 /* MPU Configuration */

void MPU_Config(void)
{
  MPU_Region_InitTypeDef MPU_InitStruct = {0};

  /* Disables the MPU */
  HAL_MPU_Disable();

  /** Initializes and configures the Region and the memory to be protected
  */
  MPU_InitStruct.Enable = MPU_REGION_ENABLE;
  MPU_InitStruct.Number = MPU_REGION_NUMBER0;
  MPU_InitStruct.BaseAddress = 0x0;
  MPU_InitStruct.Size = MPU_REGION_SIZE_4GB;
  MPU_InitStruct.SubRegionDisable = 0x87;
  MPU_InitStruct.TypeExtField = MPU_TEX_LEVEL0;
  MPU_InitStruct.AccessPermission = MPU_REGION_NO_ACCESS;
  MPU_InitStruct.DisableExec = MPU_INSTRUCTION_ACCESS_DISABLE;
  MPU_InitStruct.IsShareable = MPU_ACCESS_SHAREABLE;
  MPU_InitStruct.IsCacheable = MPU_ACCESS_NOT_CACHEABLE;
  MPU_InitStruct.IsBufferable = MPU_ACCESS_NOT_BUFFERABLE;

  HAL_MPU_ConfigRegion(&MPU_InitStruct);

  /** Initializes and configures the Region and the memory to be protected
  */
  MPU_InitStruct.Number = MPU_REGION_NUMBER1;
  MPU_InitStruct.BaseAddress = 0x30000000;
  MPU_InitStruct.Size = MPU_REGION_SIZE_32KB;  /* covers DMA descriptors + RX pool (fits in 32KB SRAM1+SRAM2) */
  MPU_InitStruct.SubRegionDisable = 0x0;
  MPU_InitStruct.TypeExtField = MPU_TEX_LEVEL1;
  MPU_InitStruct.AccessPermission = MPU_REGION_FULL_ACCESS;
  MPU_InitStruct.DisableExec = MPU_INSTRUCTION_ACCESS_ENABLE;
  MPU_InitStruct.IsShareable = MPU_ACCESS_NOT_SHAREABLE;
  MPU_InitStruct.IsCacheable = MPU_ACCESS_NOT_CACHEABLE;   /* ETH DMA region: no D-cache */
  MPU_InitStruct.IsBufferable = MPU_ACCESS_NOT_BUFFERABLE; /* no write buffer either */

  HAL_MPU_ConfigRegion(&MPU_InitStruct);
  /* Enables the MPU */
  HAL_MPU_Enable(MPU_PRIVILEGED_DEFAULT);

}

/**
  * @brief  This function is executed in case of error occurrence.
  * @retval None
  */
void Error_Handler(void)
{
  /* USER CODE BEGIN Error_Handler_Debug */
	/* Light orange LED (LED_1 / PC2) and blink 5x quickly so the fault is
	 * visible, then do a clean software reset.  Do NOT disable interrupts —
	 * that would block TIM6 and cause a supervisor WDT reset loop. */
	__HAL_RCC_GPIOC_CLK_ENABLE();
	for (int _i = 0; _i < 5; _i++) {
		HAL_GPIO_WritePin(LED_1_GPIO_Port, LED_1_Pin, GPIO_PIN_SET);
		HAL_Delay(80U);
		HAL_GPIO_WritePin(LED_1_GPIO_Port, LED_1_Pin, GPIO_PIN_RESET);
		HAL_Delay(80U);
	}
	NVIC_SystemReset();
  /* USER CODE END Error_Handler_Debug */
}
#ifdef USE_FULL_ASSERT
/**
  * @brief  Reports the name of the source file and the source line number
  *         where the assert_param error has occurred.
  * @param  file: pointer to the source file name
  * @param  line: assert_param error line source number
  * @retval None
  */
void assert_failed(uint8_t *file, uint32_t line)
{
  /* USER CODE BEGIN 6 */
  /* User can add his own implementation to report the file name and line number,
     ex: printf("Wrong parameters value: file %s on line %d\r\n", file, line) */
  /* USER CODE END 6 */
}
#endif /* USE_FULL_ASSERT */

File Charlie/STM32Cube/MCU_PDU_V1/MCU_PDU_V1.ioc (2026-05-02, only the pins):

Mcu.UserName=STM32G474RETx
PA0.GPIO_Label=FPGA_SPARE_OUT_0
PA0.Signal=GPIO_Input
PA1.GPIO_Label=FPGA_SPARE_OUT_1
PA1.Signal=GPIO_Input
PA10.GPIO_Label=CAN_STB
PA10.Signal=GPIO_Output
PA11.Signal=FDCAN1_RX
PA12.Signal=FDCAN1_TX
PA13.Signal=SYS_JTMS-SWDIO
PA14.Signal=SYS_JTCK-SWCLK
PA2.GPIO_Label=FAULT_LATCH
PA2.Signal=GPIO_Input
PA4.GPIO_Label=SPARE_ADC_0
PA4.Signal=ADC2_IN17
PA5.GPIO_Label=SPARE_ADC_1
PA5.Signal=ADC2_IN13
PA6.GPIO_Label=THERM_0
PA6.Signal=ADC2_IN3
PA7.GPIO_Label=THERM_1
PA7.Signal=ADC2_IN4
PA8.GPIO_Label=AUX_SW_2
PA8.Signal=GPIO_Output
PA9.GPIO_Label=AUX_SW_3
PA9.Signal=GPIO_Output
PB0.GPIO_Label=V_SOURCE
PB0.Signal=ADC1_IN15
PB1.GPIO_Label=V_BUS
PB1.Signal=ADC1_IN12
PB10.GPIO_Label=RS485_TX
PB10.Signal=USART3_TX
PB11.GPIO_Label=RS485_RX
PB11.Signal=USART3_RX
PB12.GPIO_Label=SW_FAULT
PB12.Signal=GPIO_Input
PB13.GPIO_Label=PGOOD_SW
PB13.Signal=GPIO_Input
PB14.GPIO_Label=RS485_DE
PB14.Signal=USART3_DE
PB15.GPIO_Label=PGOOD_24V
PB15.Signal=GPIO_Input
PB2.GPIO_Label=I_COIL
PB2.Signal=ADC2_IN12
PB3.Signal=SYS_JTDO-SWO
PB4.GPIO_Label=LED_0
PB4.Signal=GPIO_Output
PB5.GPIO_Label=BUZZER_P
PB5.Signal=S_TIM17_CH1
PB6.GPIO_Label=LED_1
PB6.Signal=GPIO_Output
PB7.GPIO_Label=BUZZER_N
PB7.Signal=TIM17_CH1N
PC1.GPIO_Label=MCU_HB
PC1.Signal=GPIO_Output
PC10.Signal=UART4_TX
PC11.Signal=UART4_RX
PC14-OSC32_IN.Signal=RCC_OSC32_IN
PC15-OSC32_OUT.Signal=RCC_OSC32_OUT
PC2.GPIO_Label=CMD_FAULT
PC2.Signal=GPIO_Output
PC3.GPIO_Label=CMD_ARM
PC3.Signal=GPIO_Output
PC4.GPIO_Label=THERM_2
PC4.Signal=ADC2_IN5
PC5.GPIO_Label=THERM_3
PC5.Signal=ADC2_IN11
PC6.Signal=I2C4_SCL
PC7.Signal=I2C4_SDA
PC8.Signal=GPIO_Output
PC9.GPIO_Label=AUX_SW_1
PC9.Signal=GPIO_Output
PF0-OSC_IN.Signal=RCC_OSC_IN
PF1-OSC_OUT.Signal=RCC_OSC_OUT

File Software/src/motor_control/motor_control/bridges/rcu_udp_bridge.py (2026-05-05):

#!/usr/bin/env python3
"""
rcu_udp_bridge.py — ROS2 node bridging RCU UDP binary protocol ↔ ROS2 topics

Replaces ethernet_can_bridge.py and nucleo_can_bridge in the PROJ500 Thor stack.

TX (Thor → RCU, port 7701):
  Subscribes /robot_command  → encodes as Type 0x10 motor cmd packets at 200 Hz
  Accepts Type 0x11 supervisory via ROS2 service /rcu_motor_estop

RX (RCU → Thor, port 7700):
  Type 0x02 motor feedback (200 Hz) → /motor_can_feedback (UInt8MultiArray)
  Type 0x04 fast IMU        (200 Hz) → /imu0, /imu1 (sensor_msgs/Imu)
  Type 0x01 slow telem      (10  Hz) → /rcu_pdu_telem (JSON String) + CSV log

Services:
    /rcu_motor_estop  (std_srvs/SetBool)
            True  → enable configured active motors only
      False → FULL E-STOP: Type 0x11 enable_mask=0 + PDU fault assert
  /rcu_pdu_fault    (std_srvs/SetBool)
      True  → assert PDU fault (cuts power rails via debug cmd 0x07)
      False → clear PDU fault

Parameters:
  rcu_ip         (str)  default "192.168.100.10"
  rcu_cmd_port   (int)  default 7701
  telem_port     (int)  default 7700
  ctrl_mode      (int)  default 0  (0=MIT impedance Phase 2, 1=CSP pos Phase 1)
  auto_enable    (bool) default False
    force_full_enable_mask (bool) default False (use 0x0FFF for supervisory enable)
  log_dir        (str)  default "~/rcu_logs"
  loop_rate_hz   (float) default 200.0  (motor command TX rate)

Usage:
  ros2 run motor_control rcu_udp_bridge
  or from the launch file: ros2 launch motor_control rcu_launch.py
"""
import os
import csv
import queue
import socket
import struct
import threading
import time
import json
import math
from collections import defaultdict
from datetime import datetime

import rclpy
from rcl_interfaces.msg import ParameterDescriptor
from rclpy.node import Node
from rclpy.qos import QoSProfile, QoSReliabilityPolicy, QoSHistoryPolicy
from sensor_msgs.msg import Imu
from std_msgs.msg import UInt8MultiArray, String
from std_srvs.srv import SetBool
from motor_control.msg import RobotCommand
HAS_ROBOT_CMD = True

from motor_control import rcu_protocol as rp

# ---------------------------------------------------------------------------
# IMU conversion constants (from rcu_protocol.py)
# ---------------------------------------------------------------------------
# decode_imu_fast already applies IMU_ACCEL_SCALE → values are in g-units.
# The policy expects a unit gravity vector ([-1, 1] range), so no further
# conversion is applied here. ACCEL_M_S2 is intentionally not used.
# ACCEL_M_S2 = 9.80665  ← removed: would produce m/s² which the policy does not expect
GYRO_RAD_S  = rp.IMU_GYRO_SCALE  * (math.pi / 180.0)  # → rad/s

# ---------------------------------------------------------------------------
# Motor feedback format for /motor_can_feedback
# Compatible with robot_observation_bridge.py "FBK" format:
# 8 bytes/motor: pos_rad (float32 LE) + vel_rads (float32 LE)
# Ordered by motor_id 1→12
# ---------------------------------------------------------------------------
FB_ENTRY_FMT = "<ff"
FB_ENTRY_SIZE = struct.calcsize(FB_ENTRY_FMT)  # 8 bytes


class RcuUdpBridge(Node):
    def __init__(self):
        super().__init__("rcu_udp_bridge")
        self._shutting_down = False

        def _parse_bool(value):
            if isinstance(value, bool):
                return value
            if isinstance(value, (int, float)):
                return bool(value)
            if isinstance(value, str):
                return value.strip().lower() in ("1", "true", "yes", "on")
            return False

        def _parse_int(value, default):
            try:
                return int(value)
            except (TypeError, ValueError):
                return default

        def _parse_float(value, default):
            try:
                return float(value)
            except (TypeError, ValueError):
                return default

        def _parse_motor_id_list(raw):
            values = raw
            if isinstance(raw, str):
                txt = raw.strip()
                if not txt:
                    values = []
                else:
                    try:
                        values = json.loads(txt)
                    except Exception:
                        # Accept simple CSV-like input: "1,2,3" or "[1,2,3]"
                        txt = txt.strip("[]")
                        values = [part.strip() for part in txt.split(",") if part.strip()]
            if isinstance(values, (int, float, str)):
                values = [values]
            if not isinstance(values, (list, tuple)):
                return []

            parsed = []
            for mid_raw in values:
                try:
                    mid = int(mid_raw)
                except (TypeError, ValueError):
                    continue
                if 1 <= mid <= 12 and mid not in parsed:
                    parsed.append(mid)
            return parsed

        # ----- Parameters -----
        self.declare_parameter("rcu_ip",       rp.RCU_IP)
        self.declare_parameter("rcu_cmd_port", rp.PORT_CMD)
        self.declare_parameter("telem_port",   rp.PORT_TELEM)
        self.declare_parameter("ctrl_mode",    0)
        self.declare_parameter("auto_enable",  False)
        self.declare_parameter("force_full_enable_mask", False)
        self.declare_parameter("log_dir",      os.path.expanduser("~/rcu_logs"))
        self.declare_parameter("loop_rate_hz", 200.0)
        self.declare_parameter("scan_motor_can_ids", False)
        self.declare_parameter("can_id_online_timeout_s", 1.0)
        self.declare_parameter("can_id_scan_log_period_s", 1.0)
        self.declare_parameter("wait_for_expected_online_ids", False)
        motor_ids_param_descriptor = ParameterDescriptor(dynamic_typing=True)
        self.declare_parameter(
            "expected_online_motor_ids", "[]", motor_ids_param_descriptor
        )
        self.declare_parameter("startup_gate_error_after_s", 5.0)
        # Keep these as strings in launch-facing APIs so IncludeLaunchDescription
        # and CLI argument overrides remain compatible on Jazzy.
        self.declare_parameter(
            "left_bus_motor_ids", "[1,3,5,7,9,11]", motor_ids_param_descriptor
        )
        self.declare_parameter(
            "right_bus_motor_ids", "[2,4,6,8,10,12]", motor_ids_param_descriptor
        )
        self.declare_parameter(
            "active_motor_ids", "[1,2,3,4,5,6,7,8,9,10,11,12]", motor_ids_param_descriptor
        )
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

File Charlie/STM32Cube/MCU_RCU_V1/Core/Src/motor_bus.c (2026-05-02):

/*
 * motor_bus.c — Motor CAN bus driver, RCU runtime build
 *
 * Peripheral ownership: FDCAN1 (right bus), FDCAN3 (left bus).
 *
 * Filter configuration for each bus:
 *   One extended-frame mask filter: ID=0, Mask=0 → accept all extended frames.
 *   Standard frames rejected (motors only send extended frames).
 *
 * Command queueing:
 *   A single pending command per motor is stored; overwritten by newer
 *   commands before they are sent.  Motor_bus_tick() sends all pending
 *   commands then clears the queue.
 */
#include "motor_bus.h"
#include "main.h"

#include <string.h>

/* -----------------------------------------------------------------------
 * Peripheral references (CubeMX-owned)
 * ----------------------------------------------------------------------- */
extern FDCAN_HandleTypeDef hfdcan1;
extern FDCAN_HandleTypeDef hfdcan3;

/* -----------------------------------------------------------------------
 * Per-bus descriptor
 * ----------------------------------------------------------------------- */
typedef struct {
    FDCAN_HandleTypeDef *hfdcan;
    GPIO_TypeDef        *stb_port;
    uint16_t             stb_pin;
    rs04_feedback_t      fb[MOTOR_MAX_PER_BUS + 1];  /* index = motor_id */
    bool                 cmd_pending[MOTOR_MAX_PER_BUS + 1];
    rs04_cmd_t           cmd[MOTOR_MAX_PER_BUS + 1];
} bus_t;

static bus_t g_bus[MOTOR_BUS_COUNT] = {
    /* Right bus: FDCAN1 */
    {
        .hfdcan   = &hfdcan1,
        .stb_port = CAN_MTR_R_STB_GPIO_Port,
        .stb_pin  = CAN_MTR_R_STB_Pin,
    },
    /* Left bus: FDCAN3 */
    {
        .hfdcan   = &hfdcan3,
        .stb_port = CAN_MTR_L_STB_GPIO_Port,
        .stb_pin  = CAN_MTR_L_STB_Pin,
    },
};

/* -----------------------------------------------------------------------
 * Helpers
 * ----------------------------------------------------------------------- */

static bool fdcan_send_ext(FDCAN_HandleTypeDef *hfdcan,
                           uint32_t ext_id,
                           const uint8_t data[8])
{
    FDCAN_TxHeaderTypeDef txh = { 0 };
    txh.Identifier          = ext_id & 0x1FFFFFFFU;
    txh.IdType              = FDCAN_EXTENDED_ID;
    txh.TxFrameType         = FDCAN_DATA_FRAME;
    txh.DataLength          = FDCAN_DLC_BYTES_8;
    txh.ErrorStateIndicator = FDCAN_ESI_ACTIVE;
    txh.BitRateSwitch       = FDCAN_BRS_OFF;
    txh.FDFormat            = FDCAN_CLASSIC_CAN;
    txh.TxEventFifoControl  = FDCAN_NO_TX_EVENTS;
    txh.MessageMarker       = 0U;
    return HAL_FDCAN_AddMessageToTxFifoQ(hfdcan, &txh, data) == HAL_OK;
}

static void init_bus(bus_t *b)
{
    /* Enable transceiver */
    HAL_GPIO_WritePin(b->stb_port, b->stb_pin, GPIO_PIN_RESET);

    /* Extended frame accept-all filter (index 0) */
    FDCAN_FilterTypeDef f = { 0 };
    f.IdType       = FDCAN_EXTENDED_ID;
    f.FilterIndex  = 0U;
    f.FilterType   = FDCAN_FILTER_MASK;
    f.FilterConfig = FDCAN_FILTER_TO_RXFIFO0;
    f.FilterID1    = 0U;   /* match any */
    f.FilterID2    = 0U;   /* mask: all bits don't care */
    (void)HAL_FDCAN_ConfigFilter(b->hfdcan, &f);

    /* Reject standard frames; pass all extended into FIFO0 */
    (void)HAL_FDCAN_ConfigGlobalFilter(b->hfdcan,
                                       FDCAN_REJECT, FDCAN_REJECT,
                                       FDCAN_FILTER_REMOTE, FDCAN_FILTER_REMOTE);

    (void)HAL_FDCAN_Start(b->hfdcan);
}

static void drain_rx(bus_t *b)
{
    FDCAN_RxHeaderTypeDef rxh;
    uint8_t rxd[8];
    rs04_feedback_t fb;

    while (HAL_FDCAN_GetRxFifoFillLevel(b->hfdcan, FDCAN_RX_FIFO0) > 0U) {
        if (HAL_FDCAN_GetRxMessage(b->hfdcan, FDCAN_RX_FIFO0, &rxh, rxd) != HAL_OK) {
            break;
        }
        if (rxh.IdType != FDCAN_EXTENDED_ID) continue;

        if (rs04_decode_feedback(rxh.Identifier, rxd, &fb)) {
            if (fb.motor_id >= 1U && fb.motor_id <= MOTOR_MAX_PER_BUS) {
                b->fb[fb.motor_id] = fb;
            }
        }
    }
}

static void flush_cmds(bus_t *b)
{
    uint8_t data[8];
    uint32_t ext_id;

    for (uint8_t id = 1U; id <= MOTOR_MAX_PER_BUS; ++id) {
        if (!b->cmd_pending[id]) continue;
        b->cmd_pending[id] = false;
        rs04_encode_cmd(id, &b->cmd[id], &ext_id, data);
        (void)fdcan_send_ext(b->hfdcan, ext_id, data);
    }
}

/* -----------------------------------------------------------------------
 * Public API
 * ----------------------------------------------------------------------- */

void motor_bus_init(void)
{
    for (uint8_t i = 0U; i < MOTOR_BUS_COUNT; ++i) {
        memset(g_bus[i].fb,          0, sizeof(g_bus[i].fb));
        memset(g_bus[i].cmd_pending, 0, sizeof(g_bus[i].cmd_pending));
        init_bus(&g_bus[i]);
    }
}

void motor_bus_tick(uint32_t now_ms)
{
    (void)now_ms;
    for (uint8_t i = 0U; i < MOTOR_BUS_COUNT; ++i) {
        drain_rx(&g_bus[i]);
        flush_cmds(&g_bus[i]);
    }
}

void motor_bus_send_cmd(uint8_t bus, uint8_t motor_id, const rs04_cmd_t *cmd)
{
    if (bus >= MOTOR_BUS_COUNT) return;
    if (motor_id < 1U || motor_id > MOTOR_MAX_PER_BUS) return;
    g_bus[bus].cmd[motor_id]         = *cmd;
    g_bus[bus].cmd_pending[motor_id] = true;
}

void motor_bus_send_enable(uint8_t bus, uint8_t motor_id,
                           bool enable, bool clear_fault)
{
    if (bus >= MOTOR_BUS_COUNT) return;
    if (motor_id < 1U || motor_id > MOTOR_MAX_PER_BUS) return;

    uint32_t ext_id;
    uint8_t  data[8];
    if (enable) {
        rs04_encode_enable(motor_id, &ext_id, data);
    } else {
        rs04_encode_stop(motor_id, clear_fault, &ext_id, data);
    }
    (void)fdcan_send_ext(g_bus[bus].hfdcan, ext_id, data);
}

const rs04_feedback_t *motor_bus_get_feedback(uint8_t bus, uint8_t motor_id)
{
    if (bus >= MOTOR_BUS_COUNT) return NULL;
    if (motor_id < 1U || motor_id > MOTOR_MAX_PER_BUS) return NULL;
    return &g_bus[bus].fb[motor_id];
}

void motor_bus_send_param_write(uint8_t bus, uint8_t motor_id,
                                uint16_t param_id, float value)
{
    if (bus >= MOTOR_BUS_COUNT) return;
    if (motor_id < 1U || motor_id > MOTOR_MAX_PER_BUS) return;
    uint32_t ext_id;
    uint8_t  data[8];
    rs04_encode_param_write(motor_id, param_id, value, &ext_id, data);
    (void)fdcan_send_ext(g_bus[bus].hfdcan, ext_id, data);
}

void motor_bus_send_set_zero(uint8_t bus, uint8_t motor_id)
{
    if (bus >= MOTOR_BUS_COUNT) return;
    if (motor_id < 1U || motor_id > MOTOR_MAX_PER_BUS) return;
    uint32_t ext_id;
    uint8_t  data[8];
    rs04_encode_set_zero(motor_id, &ext_id, data);
    (void)fdcan_send_ext(g_bus[bus].hfdcan, ext_id, data);
}
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

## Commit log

2026-02-03 saved components as meshes
    [l_ankle_link.stl, l_foot_link.stl, l_hip_pitch_link.stl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]
2026-02-03 duplicated meshes for collision
    [l_ankle_link.stl, l_ankle_link_collision.stl, l_foot_link.stl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]
2026-02-05 added the URDF file for the skeleton robot
    [skeleton.urdf]
2026-02-05 updated the file pathing for the link meshes
    [l_ankle_link_collision.stl, l_foot_link_collision.stl, l_hip_pitch_link_collision.stl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]
2026-02-05 cleaned up the formatting in skeleton.urdf file
    [skeleton.urdf]
2026-02-08 URDF file configured for the robot link and joint placements.
    [l_ankle_link.stl, l_ankle_link_collision.stl, l_foot_link.stl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]
2026-02-09 robot successfully imported into IS in correct orientation
    [robot_l_ankle_link.stl, robot_l_foot_link.stl, robot_l_hip_pitch_link.stl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]
2026-02-09 Started a fresh usd file for IS with robot imported
    [skeleton.urdf]
2026-02-15 added limits to the joints in urdf
    [robot_l_ankle_link.stl, robot_l_foot_link.stl, robot_l_hip_pitch_link.stl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]
2026-02-15 updated the joint effort and velocities at a initial values.
    [skeleton.urdf]
2026-02-15 cleaned up files in preparation for IL
    [skeleton.urdf, skeleton_limits.urdf, skeleton_manual.urdf]
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2026-02-15 added a urdf cleaner and ran it
    This removed all the values which use the scientific notation, changing those affected values with 0 instead if below a threshold. This was to ensure the urdf file would run in IS/IL
    [skeleton.urdf]
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2026-02-21 Added a reset timer to the spawn_single_robot for resetting the model.
2026-03-16 Update joint_axis_validation.py
    This script now successfully launches IS and verifies a single joint rotation axis. T
2026-03-16 Joint_limit_validation script working correctly.
    [joint_limit_results.csv]
2026-03-16 Updated the joint limit table of results to docs folder
    [joint_limit_results.csv, joint_limit_results.xlsx]
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2026-03-17 Create actuator_config.py
    Moved the actuator config details into a config file.
2026-03-17 Removed the actuator settings from the saturation script.
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2026-03-26 added power shell commands for launching the scripts
2026-04-01 fixed the orientation issue from the urdf file
    [robot.f3d, robot.step, skeleton.urdf]
2026-04-01 removed redudant fusion files
    [robot.f3d, robot.step]
2026-04-02 humanoid_stand_env.py
    Added the body contact with ground termination condition
2026-04-07 Update humanoid_walk_env.py
    Updated the walk env to start walking training. Added velocity observation and command buffer.
2026-04-08 Update humanoid_walk_env.py
    Added penalties for linear velocity in Y axis, and raw rate. This is to prevent the robot doing the crab in training and to promote forward walking.
2026-04-08 Fixed the URDF to rotate the robot 180 degrees around the Z axis as it was trying to walk backward in training.
    [skeleton.urdf]
2026-04-09 Update humanoid_walk_env.py
    Added the new penalty's to the print out
2026-04-09 Update humanoid_walk_env.py
    Added extra prints for the reward scales and also increased the ankle height threshold.
2026-04-11 Switched to explicit DCMotorCfg, added contact rewards, added actuator feedback for obs
2026-04-11 Updated the USD to correct the robot facing in the wrong direction
    [skeleton.urdf]
2026-04-13 Adding software files
    Will make sure my commits go to here in the future (sorry)
    still need to update readmes and get trhe code for connecting to motor working (this is mostly generic setup of the ros comms)
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2026-04-13 Updated the actuator settings for per joint config
2026-04-13 Update humanoid_walk_env.py
    Re-implemented per joint actuator settings. Changed the control cfg to IdealPDActuatorCfg
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2026-04-14 fixed bug to print
2026-04-14 Exported URDF again and created new USD
    [skeleton.urdf, skeleton_old.urdf]
2026-04-14 Corrected the right foot on the robot and remade the usd file.
    [robot_r_ankle_link.stl, skeleton.urdf, skeleton_example.urdf]
2026-04-14 updated the standing pose to reflect the new urdf file.
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2026-04-15 Added a print out for the actuator settings
2026-04-15 Setting up the init function for sim to real data
    Added more joint actuator config code, buffers, setting up similar to the work done in the walking training env
2026-04-20 motor test (lots of useless stuff inc)
    [MotorFeedback.json, MotorFeedbackEntry.json, MotorParam.json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]
2026-04-20 cleanup to test on thor
    [MotorFeedback.json, MotorFeedbackEntry.json, MotorParam.json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]
2026-04-20 convert_urdf_to_usd.py
    Added a config generator for joint limits.
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2026-04-23 Rewritten Code fingers crossed
    [motor_names.json]
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2026-04-23 Rework of folders and files with hopefully working motor control
    [MotorParams.json, motor_names.json]
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2026-04-23 multi motor testing fixes
2026-04-25 Added the robot final urdf and meshes
    [imu_link.stl, l_shank_link.stl, pelvis_link.stl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]
2026-04-25 Update robot.urdf
    Cleaned up the urdf file
    [robot.urdf]
2026-04-25 validation tests
    [joint_limit_results.csv]
2026-04-25 Updated the robot again after changing the unit in fusion360
    [robot.urdf]
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2026-04-25 Updated the standing_pose and actuator settings for new robot
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2026-04-25 implemented taking IMU data from imu_link rather than world frame.
2026-04-25 Update robot.urdf
    Added the oritention rotation correction
    [robot.urdf]
2026-04-25 Update convert_urdf_to_usd.py
    Added imu sensor addition with transform to the imu_link
2026-04-25 convert_urdf_to_usd.py
    fixing imu sensor implementation
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2026-04-25 added a pelvis height transform to make sure the feet are above ground, then made usd
    [robot.urdf]
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2026-04-26 Update robot.urdf
    changed the name of link
    [robot.urdf]
2026-04-26 attempting to fix orientation issue
    [robot - Copy.urdf]
2026-04-26 updated the usd with root name change
    [robot - Copy.urdf]
2026-04-26 Minor edits and cleanup
    [motor_names.json]
2026-04-27 cleaned urdf for final robot
    [robot.urdf, torso_link.stl]
2026-04-27 Revert "cleaned urdf for final robot"
    This reverts commit 2198c4d3521ca9078436860fbb202f5907892b46.
    [robot.urdf, torso_link.stl]
2026-04-27 Updated the urdf
    [robot.urdf, torso_link.stl]
2026-04-27 Update robot.urdf
    cleaner
    [robot.urdf]
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2026-04-27 New URDF
    [robot_old.urdf]
2026-04-27 URDF clean
    [robot.urdf]
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2026-04-29 small fixes with RX thread order of running ethernet
    [motor_feedback_listener.py, rcu_udp_bridge.py]
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2026-05-01 Reduced the random factor for the joint velocity and position
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2026-05-01 fixed joint_vel bug
2026-05-01 decreased the action scale to reduce jitter.
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2026-05-02 hopefully fix enable motors
    [rcu_udp_bridge.py]
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2026-05-04 reduced noise to IMU
2026-05-04 reduced joint vel noise by 50%
2026-05-04 reverted the joint vel noise reduction
2026-05-04 updated joint_torque_saturation script
    [joint_torque_saturation_results.csv]
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2026-05-05 STM32 Fixes
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2026-05-06 Charlie - Added all firmware and electrical design files
    [1EDN8511BXUSA1.SchLib, 1EDN8511BXUSA1.stp, 2016L300_16MR.stp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]

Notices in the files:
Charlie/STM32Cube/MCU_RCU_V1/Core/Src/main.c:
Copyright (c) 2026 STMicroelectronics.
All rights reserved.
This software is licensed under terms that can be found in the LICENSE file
